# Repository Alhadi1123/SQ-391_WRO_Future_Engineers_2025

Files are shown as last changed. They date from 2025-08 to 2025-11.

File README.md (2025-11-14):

<center><h1> SQ-391 WRO 2025 </center>
<p align="center">
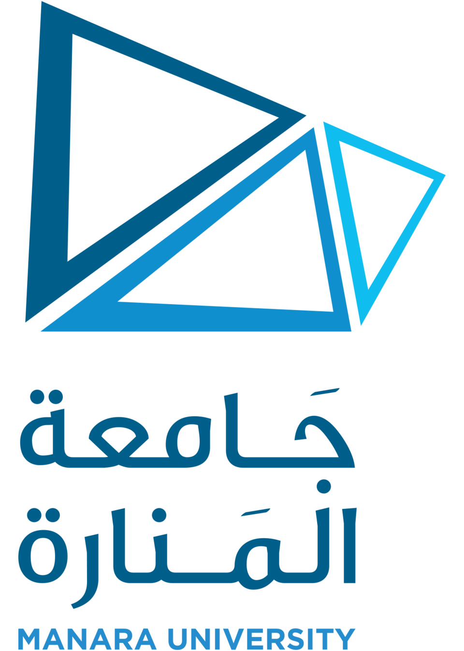
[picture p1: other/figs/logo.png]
  
</p>

<p align="center">
  <a href="https://manara.edu.sy/index.php?lang=1">
    
  </a>
  <a href="https://www.facebook.com/share/1FbUMCjNEs/">
    
  </a>
  <a href="https://www.instagram.com/manarauni?igsh=OWlpZjd6Nm52ZmV3">
    
  </a>
</p>

This repository contains the documentation for the SQ-391 team's robot for the 2025 World Robot Olympiad Future Engineers competition. The robot was designed and built by a team of three students and one coach.

## Table of Contents

- [The Team](#team)
- [The Challenge](#challenge)
- [The Robot](#robot-image)
- [Performance Video](#video)
- [Mobility Management](#mobility-management)
  - [Vehicle Main Body](#vehicle-main-body)
    - [3D Designed Parts](#3d-designed-parts)
  - [Motion Mechanism](#motion-mechanism)
    - [Ackermann Steering Mechanism](#ackermann-steering-mechanism)
    - [Differential Gear](#differential-gear)
    - [Motor Driver](#motor-driver)
  - [Wheels](#wheels)
  - [Engineering Principles](#engineering-principles)
- [Power and Sense Management](#power-and-sense-management)
  - [Electronic Parts](#electronic-parts)
  - [Overall Circuit Usage](#overall-circuit-usage)
  - [Circuit Grounding](#circuit-grounding)
  - [Power Supply](#power-supply)
  - [Overall Scheme](#overall-scheme)
  - [Wiring Diagram](#wiring-diagram)
  - [Assembly List](#assembly-list)
  - [Shopping List](#shopping-list)
- [Obstacle Management](#obstacle-management)
  - [ROS Architecture](#ros-architecture)
  - [Open Challenge](#open-challenge)
  - [Image Processing](#image-processing)
  - [Obstacle Challenge](#obstacle-challenge)
  - [Problems We Encountered](#problems-we-encountered)
- [Suggestions and Future Modifications](#suggestions-and-future-modifications)
- [Resources](#resources)

---

## The Team 

### Alhadi Zidan

<p align="center">
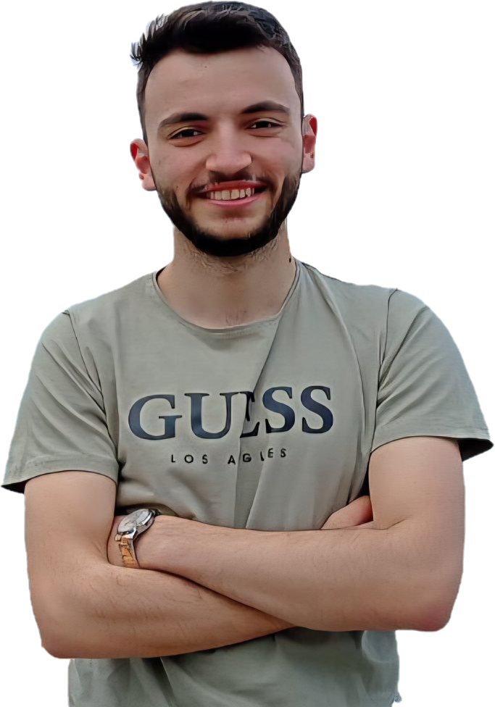
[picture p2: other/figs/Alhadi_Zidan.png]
Alhadi Zidan
  
</p>

**Role:** Coach

**Age:** 22

**Description:** Robotics and Intelligent Systems Engineer - AlManara University.

---

### Ammar Daher

<p align="center">
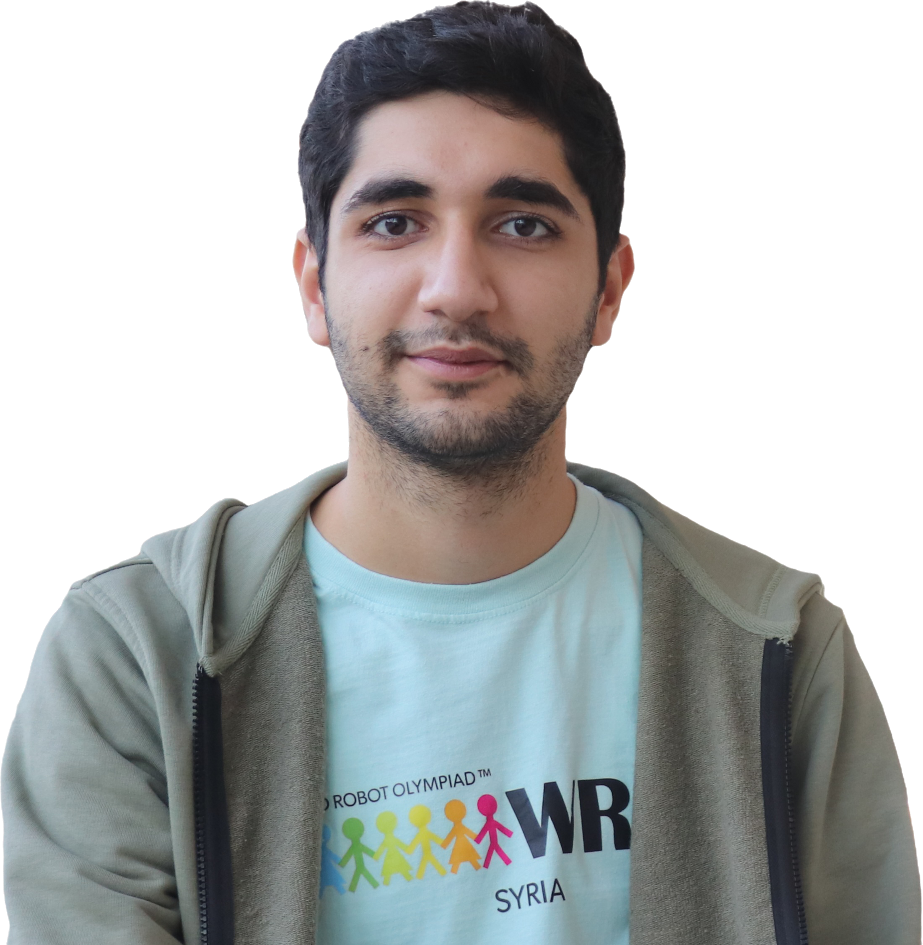
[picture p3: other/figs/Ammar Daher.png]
Ammar Daher
  
</p>

**Age:** 21

**Description:** Robotics and Intelligent Systems student at AlManara University (fifth year).

---

### Lama Alsakher

<p align="center">
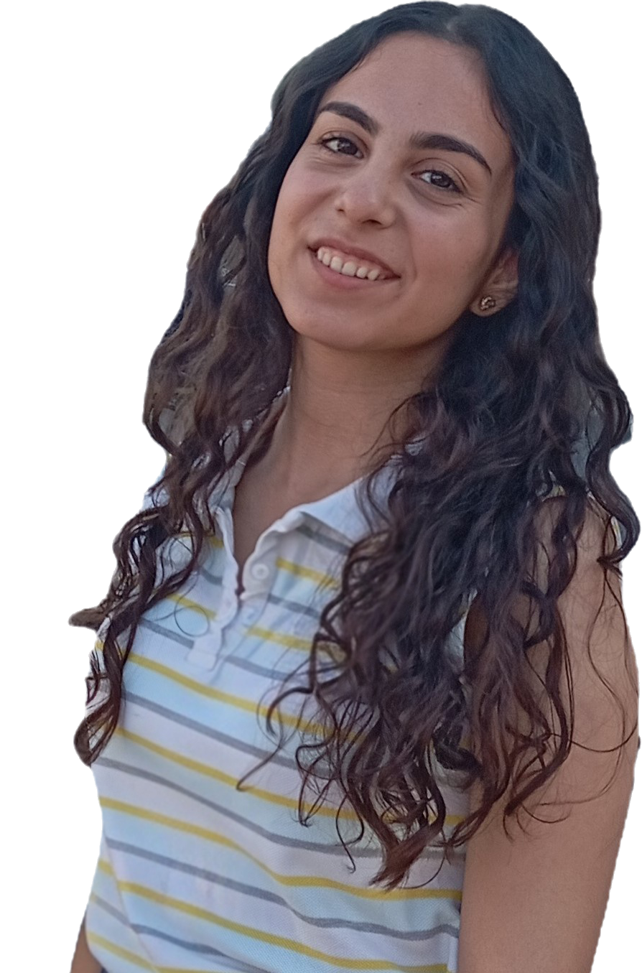
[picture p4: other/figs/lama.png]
Lama Alsakher
  
</p>

**Age:** 20

**Description:** Robotics and Intelligent Systems student at AlManara University (third year).

---

### Ibrahim Alsheikh

<p align="center">
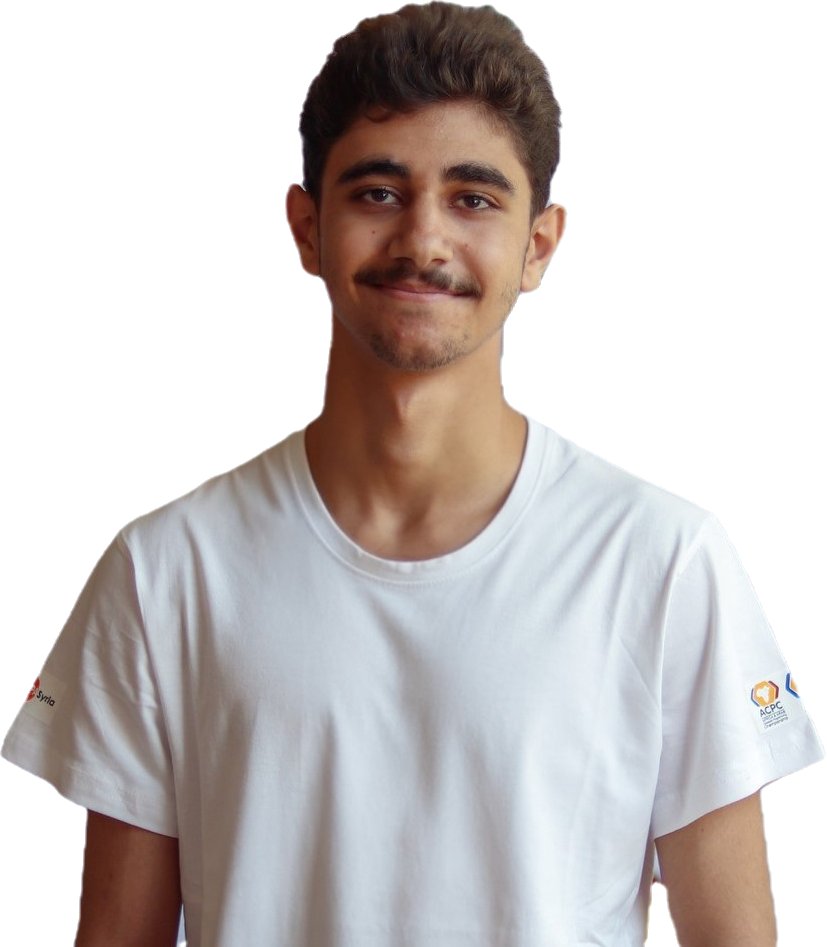
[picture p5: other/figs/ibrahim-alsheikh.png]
Ibrahim Alsheikh
  
</p>

**Age:** 20

**Description:** Robotics and Intelligent Systems student at AlManara University (third year).

---

### Team photo

<p align="center">
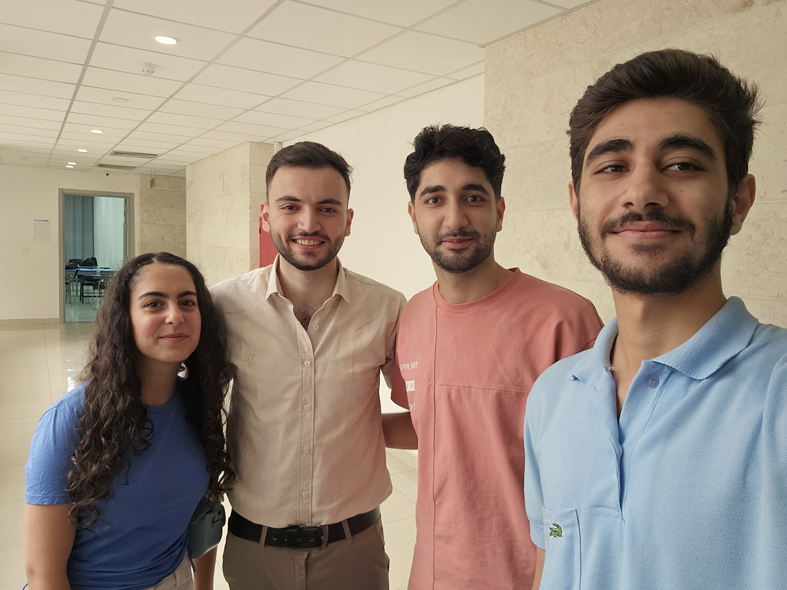
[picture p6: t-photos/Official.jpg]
Team
  
</p>

## The Challenge 

The **[WRO 2025 Future Engineers - Self-Driving Cars](https://wro-association.org/)** challenge invites teams to design, build, and program a robotic vehicle capable of driving autonomously on a racetrack that changes dynamically for each round. The competition includes two main tasks: completing laps while navigating randomized obstacles and successfully performing a precise parallel parking maneuver.

Our approach emphasizes:

- **Advanced Navigation:** Using ROS (Robot Operating System) for real-time sensor fusion and control
- **Computer Vision:** HSV-based color detection for pillar identification
- **Precision Mechanics:** Ackermann steering geometry for optimal maneuverability
- **Robust Engineering:** Systematic approach to power management and component integration

Learn more about the challenge [here](https://wro-association.org/wp-content/uploads/WRO-2025-Future-Engineers-Self-Driving-Cars-General-Rules.pdf).

## Photos of our robot 

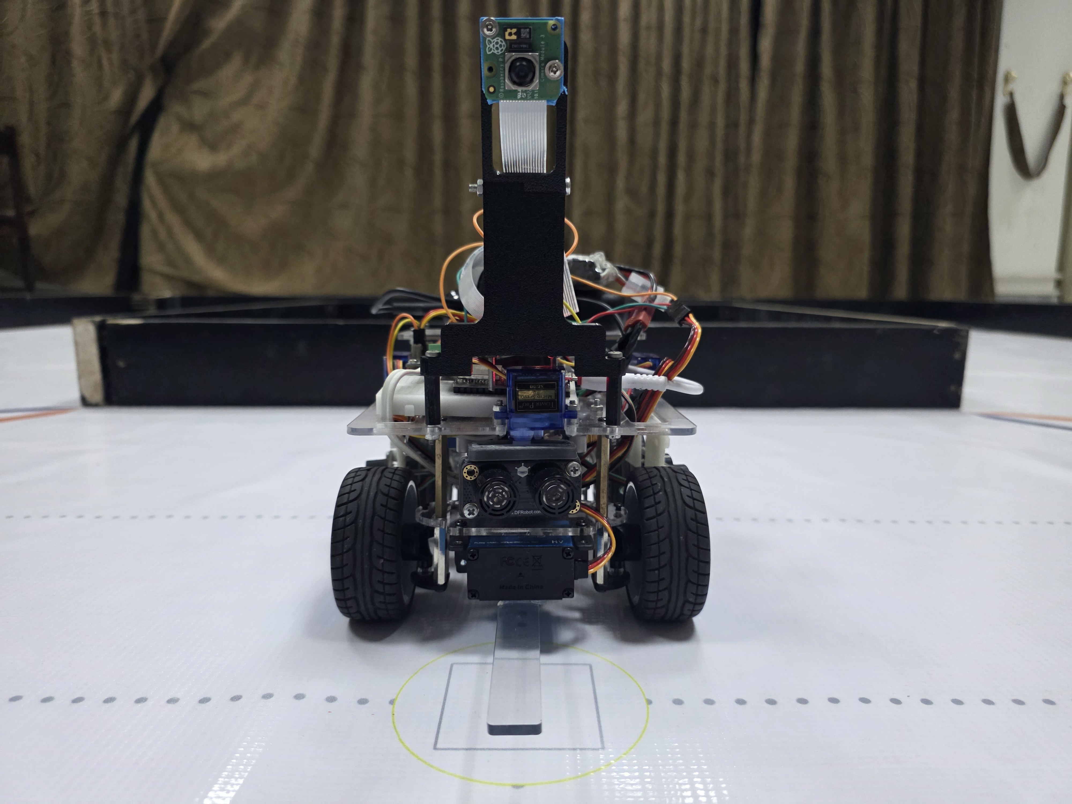
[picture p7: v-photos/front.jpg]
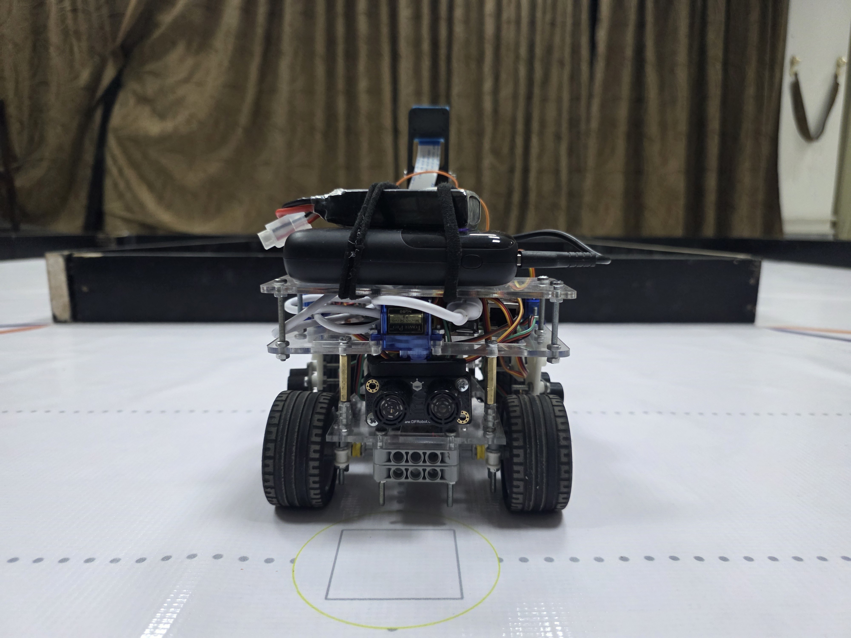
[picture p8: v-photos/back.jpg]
|  |    |
| :---: | :---: |
| _Front_ | _Back_ |
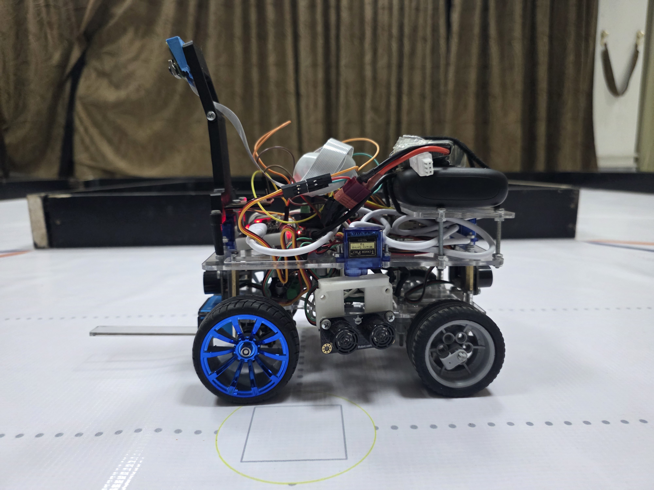
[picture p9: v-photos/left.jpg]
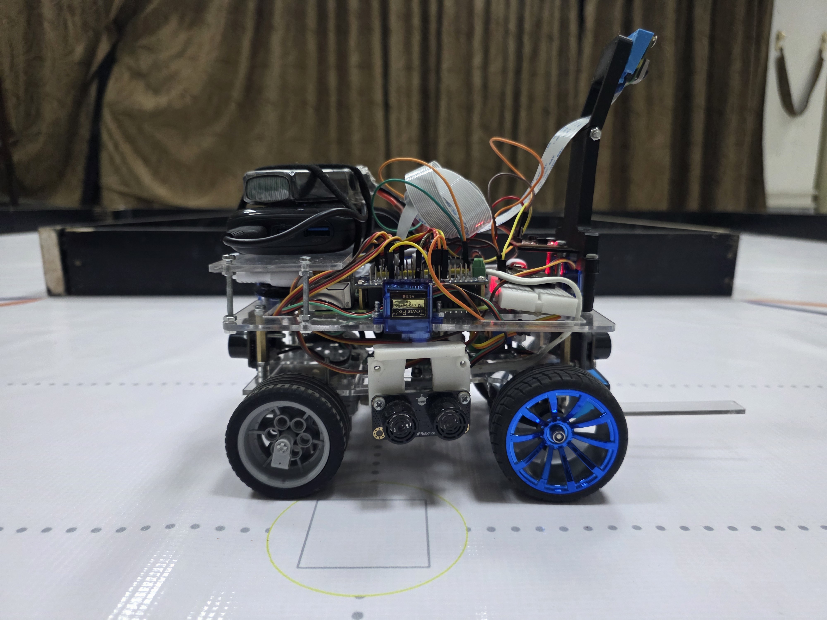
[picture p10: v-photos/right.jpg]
|   |   |
| _Left_ | _Right_ |
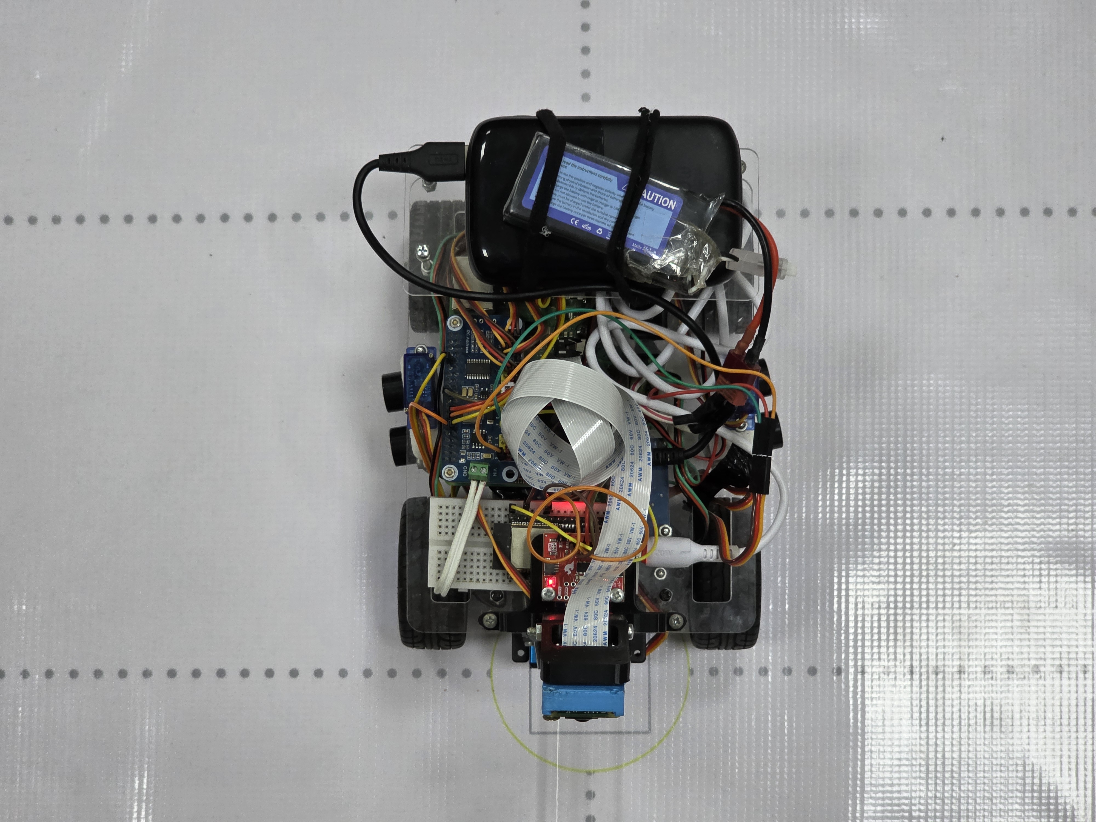
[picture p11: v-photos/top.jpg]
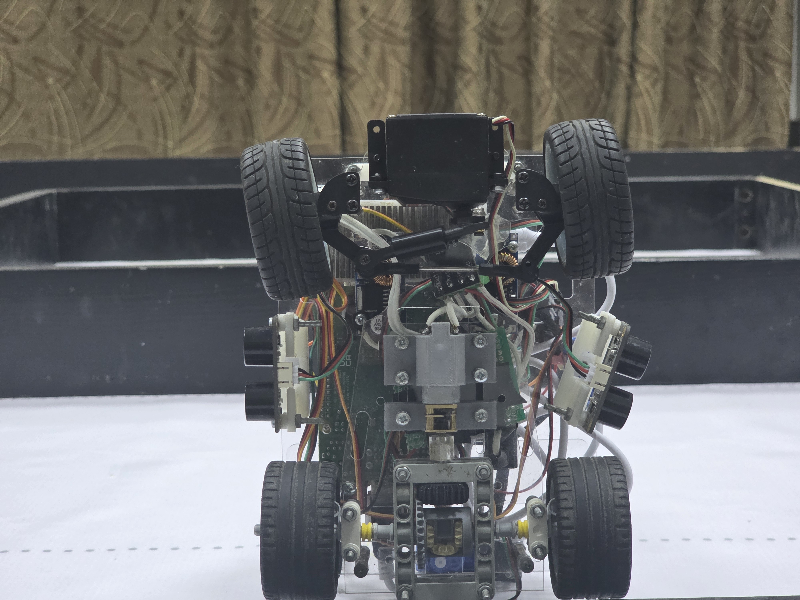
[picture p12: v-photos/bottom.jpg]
|    |  |
| _Top_ | _Bottom_ |

<br>

## Our video of the robot 

<br>
See the <a href='https://youtu.be/9q8Mh4K1foA'> Open Challenge <a/> and the <a href='https://youtu.be/HPLHJcNXbuk'> Obstacle Challenge <a/>

# Mobility Management 

## Vehicle Main Body 

Our robot is a four-wheeled vehicle constructed from two layers of Plexiglass. The upper layer accommodates the primary control and processing units, including the microprocessors, controllers, actuators, and the camera. The lower layer is dedicated to the navigation system and electrical circuit. Sensors and camera are placed in specific positions to detect the surrounding environment.

### 3D Designed Parts 

All components were designed using SOLIDWORKS. The structural parts (base and upper layer) were precision-cut using a CNC laser machine, while functional components were 3D-printed in PLA.

#### Base Layer

A structural base layer that provides mounting for the Ackermann steering and differential mechanisms on its bottom face and hosts the electronic circuit assembly on its top face.

#### Upper Layer

A structural layer that provides mounting for DC-DC converters on its underside and accommodates the Raspberry Pi, ESP, power bank, and camera assembly on its top surface. It also holds servo motors that rotate ultrasonic sensors.

#### Custom 3D-Printed Components

- **Lego-axle to DC motor axle coupler** - High precision interface connecting DC motor shaft to Lego axle.
- **Ultrasonic Sensor Holder** - Secures ultrasonic sensors to servo motors for directional scanning.
- **Camera Holder** - Two-part assembly with integrated IMU mounting.
- **DC Motor Holder** - Rigid mount that fixes the motor to the robot’s structure.
- **Support Wall** - Structural connector between chassis layers.

## Motion Mechanism 

### Ackermann Steering Mechanism 

Our design incorporates an Ackermann steering mechanism for efficient and responsive steering performance. This setup improves handling during turns and helps reduce tire wear by ensuring that each wheel follows its proper path around a corner. The inner wheel turns at a sharper angle than the outer one, allowing the robot to turn more naturally and maintain better traction.

**Key Mathematical Relations:**

For wheelbase L, front track t, and turn radius R, the ideal relations are:

```
tan(δ_in) = L/(R - t/2)
tan(δ_out) = L/(R + t/2)
```

**Steering Ratio:** The relationship between servo input angle and resulting road-wheel angle:

```
SR = θ_input / δ_avg
δ_avg ≈ θ_input / SR
```

**Servo Torque:** Required actuator torque:

If M_req is the required steering moment at the road-wheel side, η is the mechanism efficiency (typically 0 <η ≤ 1), then:

```
τ_servo ≈ M_req / (SR × η)
```

**Turning Radius:**

```
R ≈ L / tan(δ_avg)
```

### Differential Gear 

We implemented a differential gearbox system that ensures the rear wheels can spin at different rates while maintaining balanced power distribution. This component plays a crucial role in maintaining smooth and controlled movement, particularly when the robot is turning or when one wheel has less traction than the other. By balancing the torque between both wheels, the differential gear helps prevent skidding and ensures stable movement. We started by using LEGO gears, but because of their low stability, we decided to design and illustrate a customized ring gear by 3d printing and implement it in the mechanism. 

**Components:**

- Ring Gear: Large gear receiving power from the motor
- Pinion Gear: Smaller gear connecting to the drive shaft
- Side Gears: Two gears linking the differential to the axle shafts
- Spider Gears: Allow wheels to rotate at varying speeds

**Gear Ratio Calculation:**

```
GR = R/S1 + R/S
```

Where R is ring gear teeth, S1 and S2 are side gear teeth.

The wheel speed (N_wheel) can be derived from the motor’s no-load speed (N_Motor_no_load) using the formula:

```
N_wheel = N_Motor_no_load / GR
```

### Motor Driver 

The DRV8871 H-bridge motor driver provides:

- **Current Capability:** Up to 3.5A continuous, 3.6A peak
- **Voltage Range:** 6.5-45V input
- **PWM Control:** 0-200kHz recommended frequency
- **Protection:** Overcurrent, thermal shutdown, undervoltage lockout
- **Control:** Simple two-pin interface (IN1, IN2)

## Wheels 

**Specifications:**

- **Diameter:** 65mm
- **Width:** 25-30mm
- **Material:** Rubber tire with plastic hub
- **Weight:** Lightweight for optimal performance (20-21 g)
- **Coupling:** Compatible with hex connections

## Engineering Principles 

1. **Torque and Speed Balance:** Motor selection based on τ = F × r relationship
2. **Power Output:** Verification using P = τ × ω, providing 4.2W sufficient power
3. **Weight Distribution:** Strategic component placement for stability
4. **Maneuverability:** Differential drive system with ~0.1m turning radius
5. **Energy Efficiency:** Optimized gear ratios for peak efficiency operation

# Power and Sense Management 

## Electronic Parts 

### ESP32-WROOM-32E

| **Feature** | **Details / Image** |
|---|---|
| **Core** | Dual-core Xtensa® LX6 up to 240 MHz |
| **Memory** | 520 KB SRAM, 4 / 8 / 16 MB QSPI flash, optional 2 MB PSRAM |
| **Wireless** | Wi-Fi 802.11 b/g/n (2.4 GHz), Bluetooth 4.2 + BLE |
| **I/O** | Up to 26 GPIOs (3.3 V), 2× 12-bit ADC, 2× 8-bit DAC, 10 touch inputs |
| **Interfaces** | UART × 3, SPI × 4, I²C × 2, I²S, PWM, CAN (TWAI), SD/MMC, Ethernet MAC |
| **Supply** | 3.0 – 3.6 V (typ. 3.3 V), ≥ 500 mA recommended |
| **Operating Temp** | −40 °C to 85 °C (105 °C for H variants) |
| **Programming** | UART-based flashing via CP2102 / CH340 bridge |
| **Form Factor** | 18 × 25.5 × 3.1 mm, 38 castellated pads |
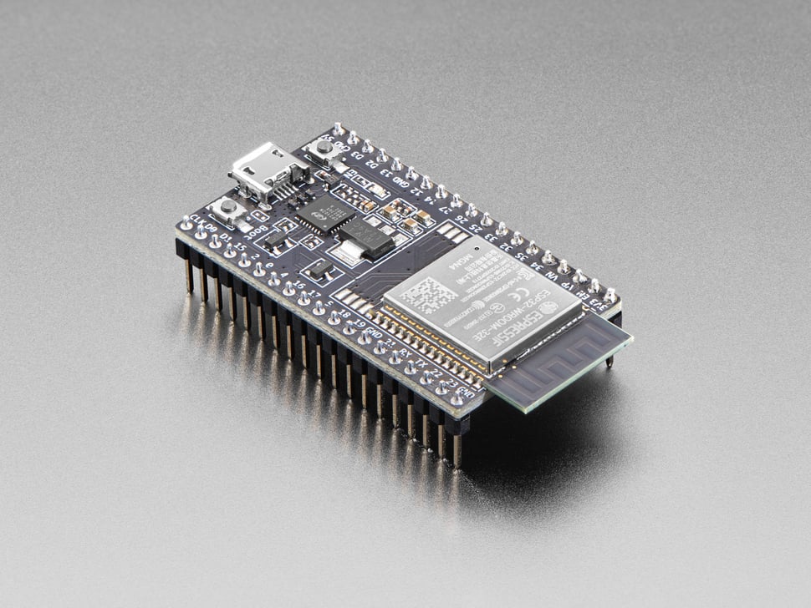
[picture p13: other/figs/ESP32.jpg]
ESP32-WROOM-32E
| **Image** | <div align="center"> |

### Raspberry Pi 4 Model B

| **Feature** | **Details / Image** |
|---|---|
| **Processor** | Broadcom BCM2711, quad-core Cortex-A72 (ARM v8) 64-bit SoC @ 1.5 GHz |
| **Memory** | Up to 8 GB LPDDR4 RAM |
| **Connectivity** | Dual-band Wi-Fi (2.4/5.0 GHz 802.11b/g/n/ac), Bluetooth 5.0 + BLE, Gigabit Ethernet |
| **USB Ports** | 2 × USB 3.0, 2 × USB 2.0 |
| **GPIO** | 40-pin header (backward-compatible with earlier boards) |
| **Video & Sound** | 2 × micro HDMI (up to 4Kp60), MIPI DSI/CSI, 4-pole audio + video jack |
| **Multimedia** | H.265 4Kp60 decode, H.264 1080p60 decode / 1080p30 encode, OpenGL ES 3.0 |
| **Storage** | Micro SD card slot for OS and data |
| **Power Input** | 5 V DC via USB-C (≥ 3 A) or GPIO header; PoE supported (via PoE HAT) |
| **Environment** | Operating temperature 0–50 °C; in production until ≥ 2034 |
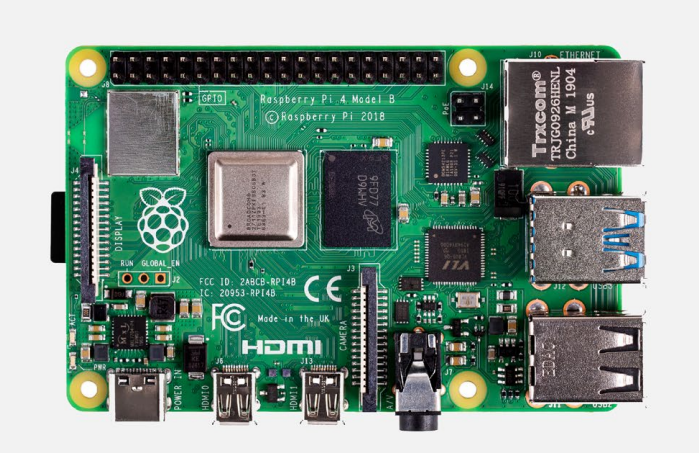
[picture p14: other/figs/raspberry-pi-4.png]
Raspberry Pi 4
| **Image** | <div align="center"> |

### Raspberry Pi Camera Module 3

| **Feature** | **Details / Image** |
|---|---|
| **Sensor** | Sony IMX708, 11.9 MP, 4608 × 2592 px (1/2.43″ optical size) |
| **Pixel Size** | 1.4 µm × 1.4 µm |
| **Focus** | Motorized, depth of field ≈ 5 cm – ∞ |
| **Focal Length** | 2.75 mm, F / 2.2 |
| **Field of View** | 102° (H) × 67° (V) |
| **Max Exposure** | 112 s |
| **Video Modes** | 2304 × 1296 @ 56 fps, 2304 × 1296 @ 30 HDR, 1536 × 864 @ 120 fps |
| **Size / Weight** | 25 × 24 × 12.4 mm; ≈ 4 g |
| **NoIR Version** | Unavailable |
| **Interface** | CSI connector (Raspberry Pi compatible) |
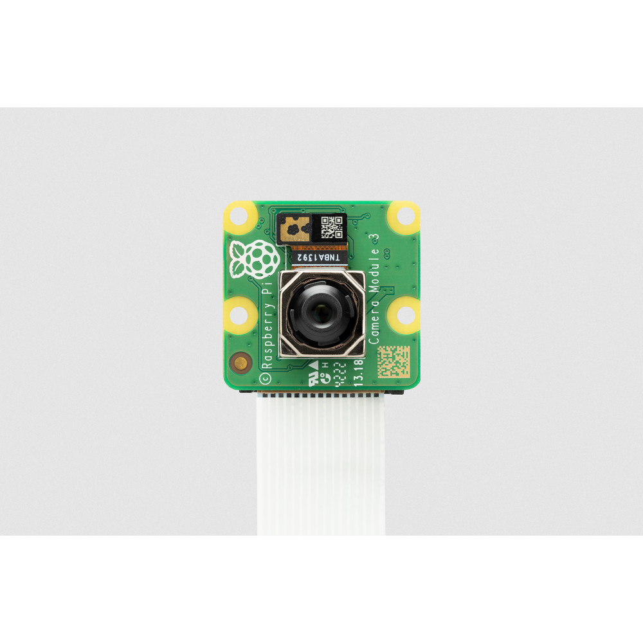
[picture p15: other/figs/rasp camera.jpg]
Raspberry Pi Camera Module 3
| **Image** |  |

### BN0086 (Qwiic) IMU Sensor

| **Feature** | **Details / Image** |
|---|---|
| **Type** | 9-DoF IMU – 3-axis accelerometer, 3-axis gyroscope, 3-axis magnetometer |
| **Sensor Fusion** | On-chip Cortex-M0+ running SH-2 firmware (quaternion + rotation vector output) |
| **Interfaces** | I²C (Qwiic, 3.3 V logic, up to 400 kHz), SPI, UART |
| **I²C Address** | 0x4B (default), optional 0x4A via solder jumper |
| **Output Data** | Rotation Vector (9-axis), Game Rotation (6-axis), Linear Accel, Gravity, Raw Sensor Data |
| **Supply Voltage** | 3.3 V (Qwiic connector) |
| **Interrupt** | INT pin for event-driven reporting; configurable update rate (tens–hundreds Hz) |
| **Calibration** | Auto gyro/accel bias; magnetometer requires hard/soft-iron calibration |
| **Mounting** | Align IMU frame (X,Y,Z) with robot frame; minimize vibration and magnetic interference |
| **Use Case** | Absolute and relative orientation tracking for robotics, mapping, and navigation |
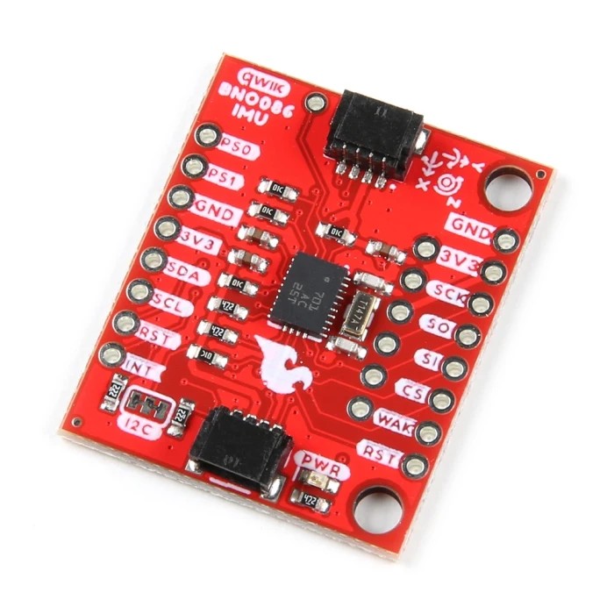
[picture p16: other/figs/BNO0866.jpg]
BN0086 (Qwiic) IMU Sensor
| **Image** |  |

### DRV8871 Motor Driver

| **Feature** | **Details / Image** |
|---|---|
| **Type** | Single H-bridge brushed DC motor driver (Texas Instruments) |
| **Topology** | Full H-bridge using 4 N-MOSFETs; R<sub>DS(on)</sub> ≈ 565 mΩ |
| **Current Capability** | Up to 3.5 A continuous, 3.6 A peak |
| **Supply Voltage (VM)** | 6.5 – 45 V |
| **Control Inputs** | IN1 / IN2 logic pins (forward, reverse, brake, coast) |
| **Logic Levels** | 0 – 5.5 V; internal pulldowns ≈ 100 kΩ |
| **PWM Control** | 0 – 200 kHz; effective duty range ≈ 16 – 84 |
| **Current Regulation** | Integrated sensing; programmable limit via ILIM resistor |
| **Protections** | UVLO, overcurrent (OCP ≈ 3.7 – 6.4 A), thermal shutdown (TSD) |
| **Package** | 8-pin HSOP (DDA) with PowerPAD™ (≈ 4.9 × 6.0 mm) — tie pad to GND plane |
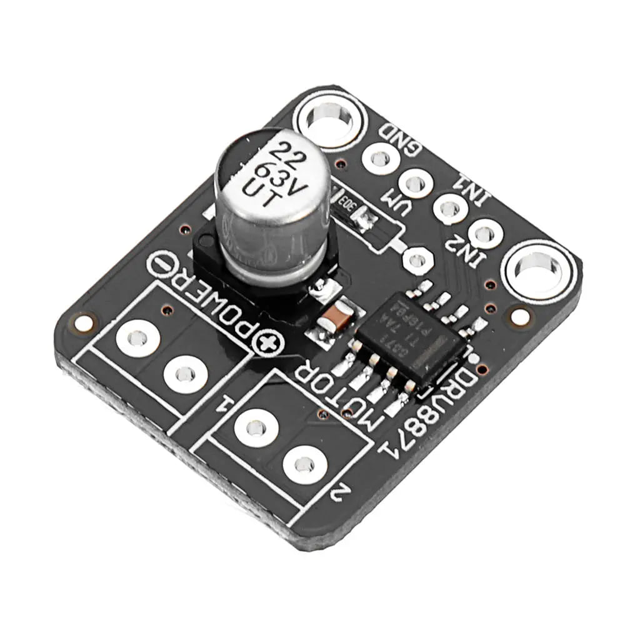
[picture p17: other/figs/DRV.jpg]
DRV8871 Motor Driver
| **Image** |  |

### URM09 Ultrasonic (Trig)

| **Feature** | **Details / Image** |
|---|---|
| **Type** | Ultrasonic distance sensor (single-wire Trig/Echo via TDM) |
| **Range** | 2 – 500 cm |
| **Resolution** | 1 cm; Accuracy ≈ 1 |
| **Measurement Rate** | Up to 25 Hz (Trig variant) |
| **Interface** | Single digital I/O (Trig + Echo multiplexed) |
| **Timing** | 10 µs trigger pulse; max echo ≈ 35 ms |
| **Supply Voltage** | 3.3 – 5.5 V; Current < 20 mA |
| **Field of View** | ≈ 60° beam angle |
| **Size** | 47 × 22 mm (3-pin PH2.0 connector: +, –, D) |
| **Integration Notes** | Fire one sensor at a time; wait > 40 ms between pings to avoid cross-talk |
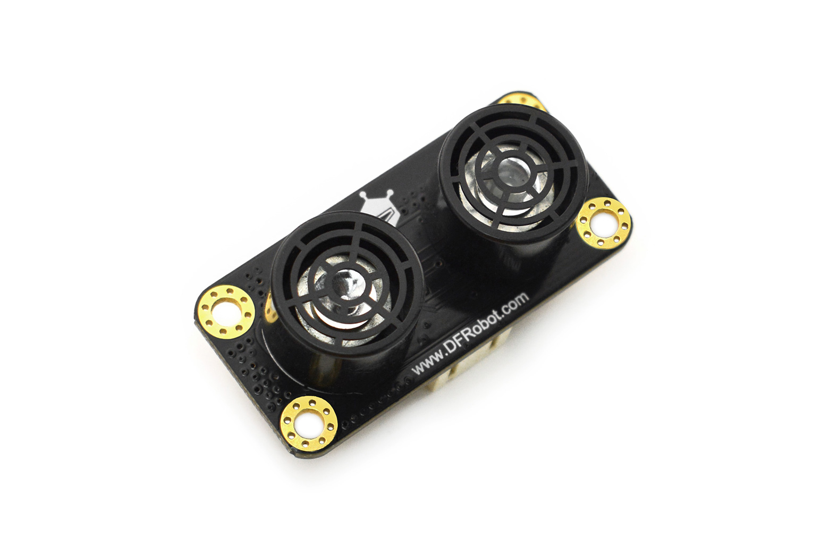
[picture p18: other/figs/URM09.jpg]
URM09 Ultrasonic (Trig)
| **Image** |  |

### Core DC Motor (6 V, 400 RPM)

| **Feature** | **Details / Image** |
|---|---|
| **Type** | Brushed DC motor with metal gearbox (carbon brushes) |
| **Nominal Voltage** | 6 V DC |
| **Gear Ratio** | 48 : 1 |
| **No-Load Speed** | ≈ 400 RPM ; No-Load Current ≈ 120 mA |
| **Torque** | Continuous ≈ 1.2 kg·cm (0.118 N·m), Stall ≈ 3.9 kg·cm (0.382 N·m) |
| **Stall Current** | ≈ 3.2 A |
| **Mechanical** | Size ≈ 47 × 15 × 10 mm ; Weight ≈ 21 g ; 3 mm D-shaft (8 mm L) |
| **Recommended Driver** | H-bridge ≥ 3.2 A peak, PWM speed control (tens kHz range) |
| **Notes** | Operable up to 15 V (short duration) ; avoid stall for thermal safety |
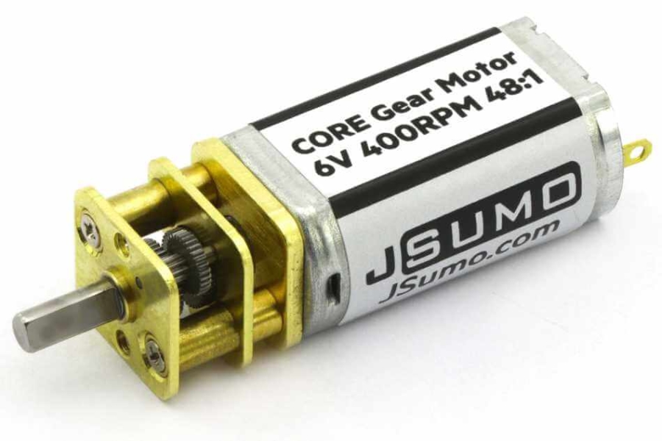
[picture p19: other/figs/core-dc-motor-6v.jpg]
Core DC Motor 6V 400RPM
| **Image** |  |

### TowerPro MG996R Servo

| **Feature** | **Details / Image** |
|---|---|
| **Type** | High-torque, metal-gear hobby servo |
| **Operating Voltage** | 4.8 V – 7.2 V |
| **Stall Torque** | 12 kg·cm (at 6 V) |
| **Speed** | 0.2 s / 60° (at 6 V) |
| **Control Signal** | Standard PWM (1 – 2 ms pulse width) |
| **Gear Type** | All-metal gears for durability and strength |
| **Dimensions** | 40.7 × 19.7 × 42.9 mm ; Weight ≈ 55 g |
| **Connector** | JR (universal 3-pin type) |
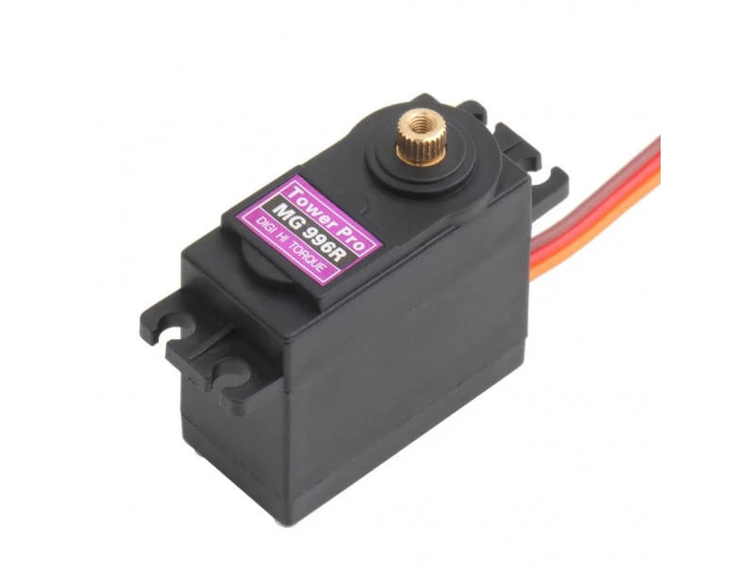
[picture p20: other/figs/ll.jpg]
TowerPro MG996R Servo
| **Image** |  |

### Micro Servo Motor SG90

| **Feature** | **Details / Image** |
|---|---|
| **Type** | 9 g micro servo with plastic gears and PWM control |
| **Operating Voltage** | 4.8 – 6.0 V (nominal 5 V) |
| **Rotation Range** | ≈ 180° mechanical (160–170° usable via PWM) |
| **Speed** | ≈ 0.12 s / 60° at 4.8 V |
| **Torque** | ≈ 1.8 kg·cm (0.176 N·m) at 4.8 V |
| **Current Draw** | 10–15 mA idle, 100–250 mA typical, ≥ 650 mA stall |
| **Dimensions** | 22.8 × 12.2 × 29.4 mm ; Weight ≈ 9 g |
| **Control Signal** | 50 Hz PWM (1.0–2.0 ms pulse width, 1.5 ms center) |
| **Mounting** | Includes horns and screws; Futaba-compatible 21T spline (4.8 mm) |
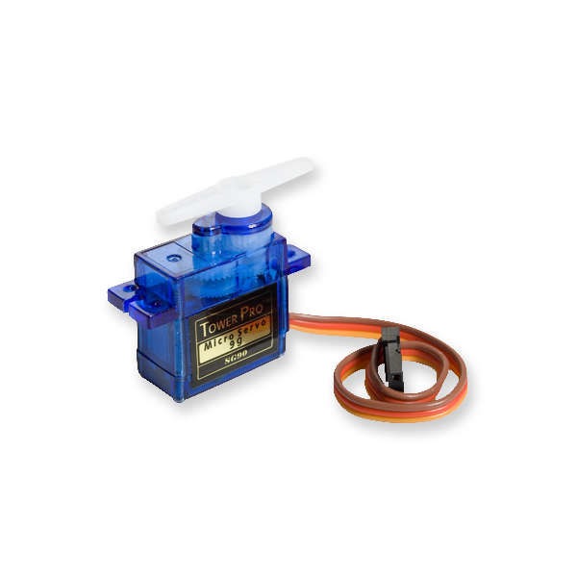
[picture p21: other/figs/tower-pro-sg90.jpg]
Micro Servo Motor SG90
| **Image** |  |

### PCA9685 Servo Driver HAT

| **Feature** | **Details / Image** |
|---|---|
| **Controller** | PCA9685 – 16-channel, 12-bit PWM generator with I²C interface |
| **PWM Frequency** | Programmable 24 Hz – 1.5 kHz ; use 50–60 Hz for hobby servos |
| **Resolution** | 12-bit (4096 steps) → 4.88 µs per step @ 50 Hz |
| **Servo Rail Voltage** | 5 V (up to 3 A continuous total output) |
| **Input Power** | 5 V from Pi header (light load) or 6–12 V via VIN (recommended) |
| **I²C Bus** | 3.3 V logic; default address 0x40; A0–A4 jumpers for stacking (up to 32 devices) |
| **Isolation** | For high-current servos, cut 0 Ω link and power via VIN while isolating Pi 5 V |
| **Form Factor** | 65 × 30 mm HAT ; 3 mm mounting holes ; straight or right-angle header variant |
| **Integration Notes** | Calibrate servo end-stops ; ensure bulk capacitors on 5 V line |
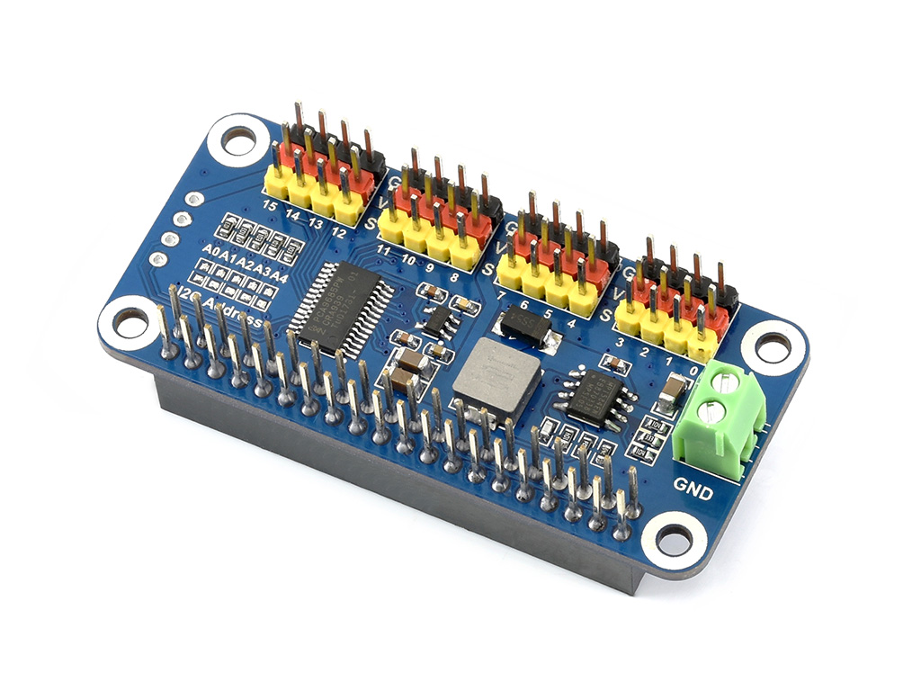
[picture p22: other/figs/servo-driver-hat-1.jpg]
PCA9685 Servo Driver HAT
| **Image** |  |

### Power Supply Components

- **Primary Battery:** 2S LiPo (7.4V, 2200mAh, 50C) with Deans connector
- **Raspberry Pi Power:** INIU 10,000mAh USB-C power bank (22.5W)
- **Voltage Regulation:** XL4005 DC-DC step-down converters
- **Current Distribution:** PCA9685 servo driver board

## Overall Circuit Usage 

Our power management strategy employs dual power domains:

1. **Control Domain:** Raspberry Pi powered by dedicated USB power bank
2. **Actuation Domain:** Motors and sensors powered by a LiPo battery

**Current Specifications:**

| Component | Supply Voltage | Idle Current | Active Current | Peak Current |
| --- | --- | --- | --- | --- |
| Raspberry Pi 4 | 5.1V | ~540mA | ~1.0-1.3A | up to 3.0A |
| Camera Module  | 5V | -- | ~200-250mA | ~300-350mA |
| ESP32 | 3.3V | <5µA | ~50-80mA | ~120-200mA |
| BNO086 IMU | 3.3V | ~3mA | ~3-10mA | -- |
| URM09 Sensors  | 5V | -- | <20mA | -- |
| MG996R Servo | 6V | ~10-20mA | ~500-900mA | ~2.0-2.5A |
| Core DC Motor  | 6V | -- | ~200-400mA | ~2.2A |

## Circuit Grounding 

Proper grounding ensures stable operation by providing a common electrical reference point for all components. Our star-grounding scheme minimizes electrical noise and prevents ground loops that could affect sensor readings.

## Power Supply 

The separated power architecture prevents motor-induced voltage drops from affecting the Raspberry Pi, ensuring uninterrupted operation of the control system during high-current motor operations.

## Overall Scheme 

<p align="center">
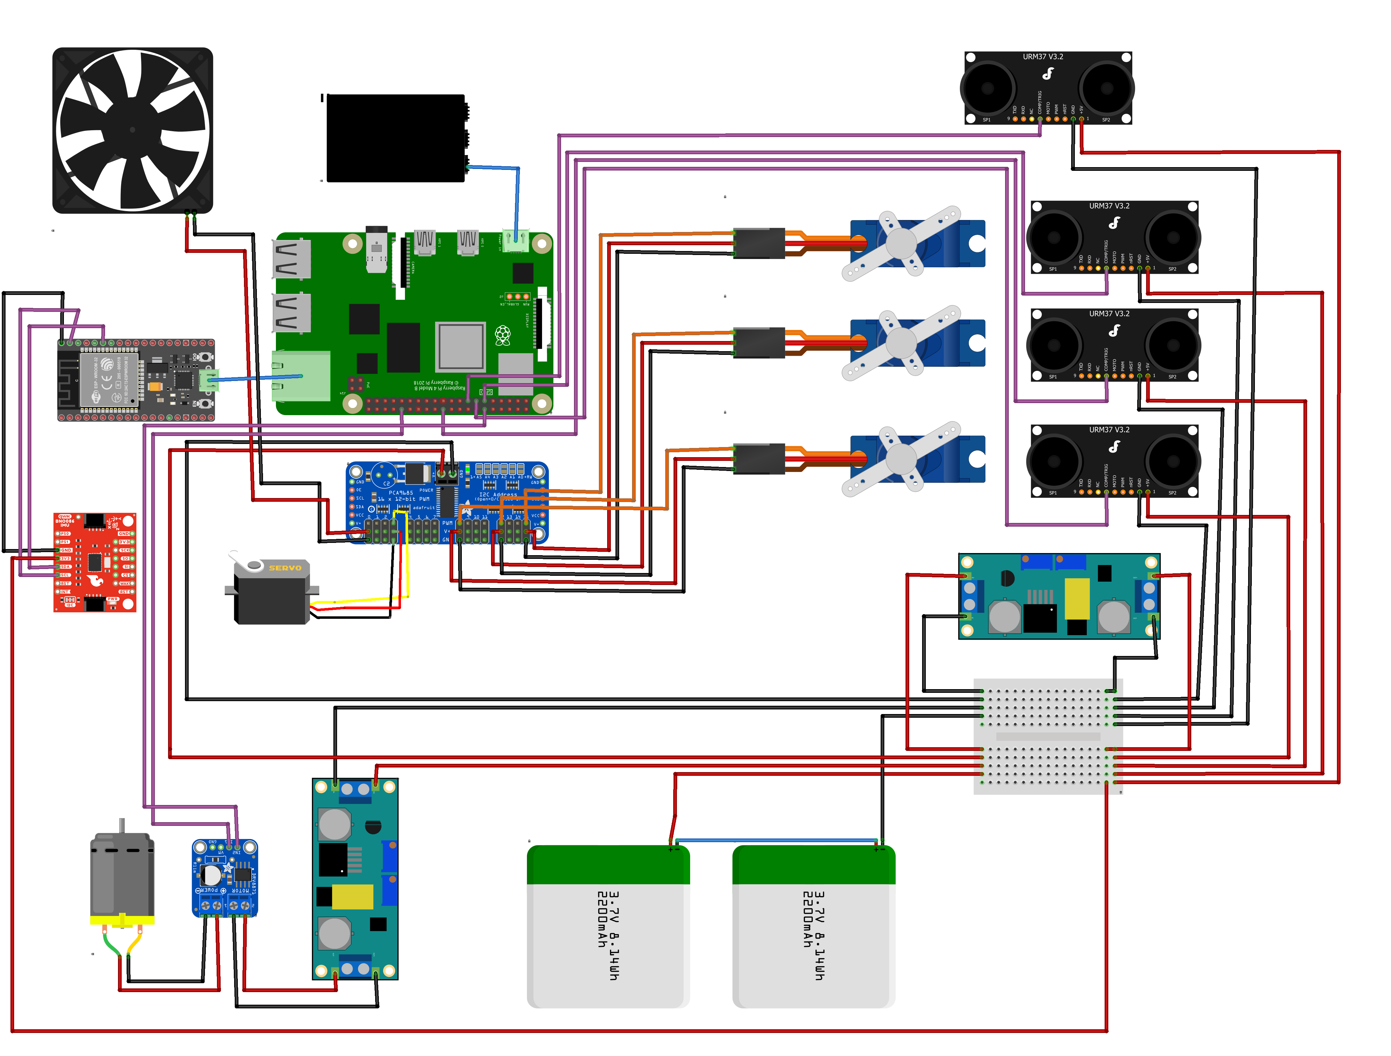
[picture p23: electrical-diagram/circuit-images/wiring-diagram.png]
  
</p>

## Wiring Diagram 

<p align="center">
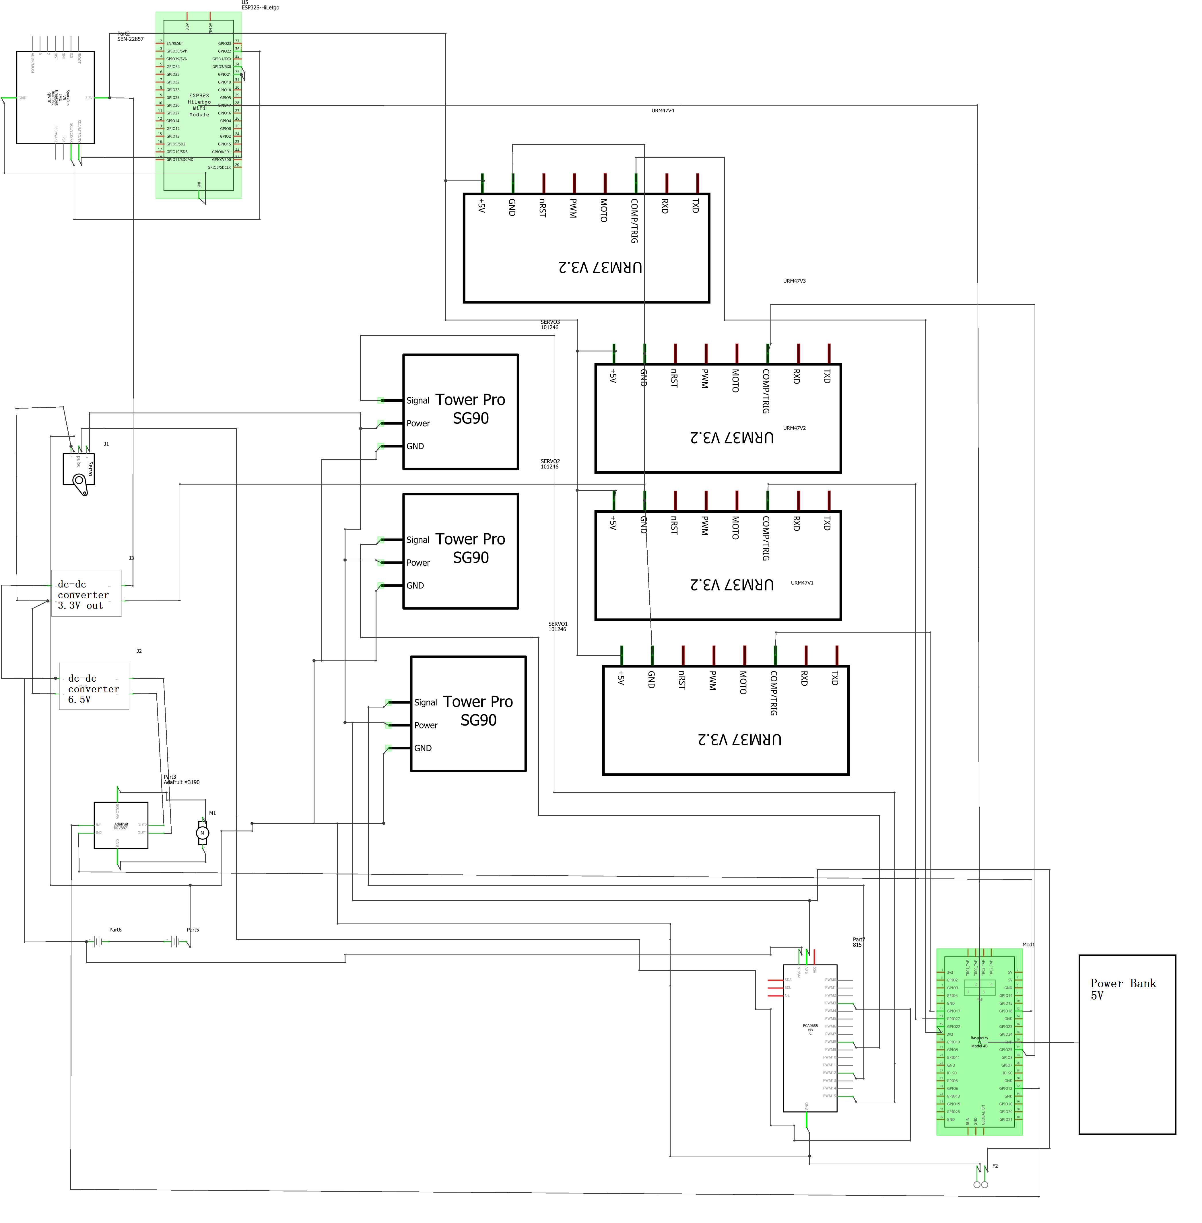
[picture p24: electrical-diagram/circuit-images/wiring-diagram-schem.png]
  
</p>

## Assembly List 

| Label | Part Type | Properties |
| --- | --- | --- |
| Mod1 | Raspberry Pi 4B  | BCM2711 Quad-core Cortex-A72 @1.5GHz |
| U5 | ESP32S-HiLetgo | 38 pins, NudeMCU-32S variant |
| Part2 | SparkFun BNO086  | VR IMU Breakout (Qwiic) |
| Part3 | Adafruit DRV8871 | H-bridge motor driver |
| Part7 | PCA9685 | PWM/Servo breakout board |
| M1 | JSUMO Core Motor | 6V 400 RPM with 48:1 gearing |
| J1 | TowerPro MG996R  | High-torque servo motor |
| SERVO1-3 | TowerPro SG90 | Micro servo motors |
| URM1-4 | URM09 | Ultrasonic distance sensors |
| Part4 | INIU Power Bank  | 10,000mAh USB-C in/out |
| Part5-6  | LiPo Battery | 2200mAh 2S configuration |

## Shopping List 

| Qty | Part | Unit Price (€) | Total (€)  |
| --- | --- | --- | --- |
| 1 | Raspberry Pi 4B (4GB) | 61.08 | 61.08 |
| 1 | ESP32 Dev Kit | 11.49 | 11.49 |
| 1 | SparkFun BNO086 | 49.90 | 49.90 |
| 1 | Adafruit DRV8871 | 7.68 | 7.68 |
| 1 | PCA9685 Servo Board | 40.79 | 40.79 |
| 1 | JSUMO Core Motor | 12.50 | 12.50 |
| 1 | TowerPro MG996R | 12.00 | 12.00 |
| 3 | TowerPro SG90 | 2.99 | 8.97 |
| 4 | URM09 Sensors | 14.50 | 58.00 |
| 1 | Power Bank 10Ah | 29.95 | 29.95 |
| 2 | LiPo 2200mAh | 19.99 | 39.98 |
| 2 | XL4005 DC-DC | 4.92 | 9.84 |
| 1 | Cooling Fan | 1.99 | 1.99 |
| **Total** | | | **343.77** |

# Obstacle Management 

Our main algorithm for both challenges relies on the robot’s ability to move to a specified distance (threshold) from the inner or outer wall and then follow that offset to navigate between sections. We achieve this using ultrasonic sensors mounted on SG90 servos that rotate the sensors to face the wall, as shown in the following figure, providing accurate measurements of the robot’s distance on all four sides. To achieve that, we used an IMU sensor (BNO086) to estimate the robot’s angle during a run. Because we have multiple sensors, actuators, and controllers, our software stack is built with ROS Noetic (ROS 1) on Raspberry Pi OS Bookworm (ARM64), which handles real-time acquisition, synchronization, and processing of all sensor streams.

<p align="center">
  case4
</p>

## ROS Architecture 

Our robot utilizes ROS Noetic for real-time sensor fusion and control:

**Node Structure:**

- **Control Node:** Central processing and decision making
- **Ultrasonic Node:** Range measurements at 25Hz
- **IMU Node:** Orientation data via rosserial bridge
- **Camera Node:** On-demand pillar detection service
- **Actuator Nodes:** Motor and servo command execution

**Communication:**

- Topics: `/ultra_sensors`, `/gyro_sensor`
- Services: `/detect_pillars` for vision processing
- Parameters: Dynamic reconfiguration for field tuning

## Open Challenge 

In the Open Challenge, the goal is to complete three laps without touching the walls and in the shortest possible time. We keep the robot centered in the lane by computing the difference between the right and left distance sensors and regulating this error toward zero during navigation. To improve the rate of change of this error, we also regulate the angle error—the difference between the current yaw (robot orientation) and the desired reference. This yields low overshoot when converging to the centerline and smooth motion transitions. To move to the next section, we detect corners using the side ultrasonic sensors, then adjust the desired robot angle reference by ±90° depending on the round direction.

### Navigation Strategy

We employ a dual-error PID controller that regulates the robot's angle and distances from the walls. The `pid_control` function shown below computes the distance error as the difference between the current and desired distances from the inner and outer walls, and the angle error as the difference between the current robot orientation and the desired reference angle. These errors are weighted by their respective proportional gains, kp1 and kp2, to generate a correction value at each control cycle. The final steering angle to be applied is then determined from this correction.

**Error Functions:**

```
e_θ(t) = wrap(θ(t)) - wrap(θ_ref)
e_d(t) = d_R(t) - d_L(t)
```

```python
def pid_control(kp1=0.5,kp2=-0.45,kd2=0,speed=max_speed,threshold=0,dists=[30]*4):
    #PID control loop to adjust steering and maintain distance balance.
    global prev_dist_err,steering, dist_err
    dist_err = dists[l] - dists[r]+threshold*dir1
    angle_err=yaw+float(dir1*sec*90)
    corr=kp1*(angle_err)+(kp2*(dist_err)+kd2*(dist_err-prev_dist_err))*(abs(dist_err)>0)
    
    # Limit correction to safe range
    corr = max(min(corr,25),-25)
    
    steering = steering_angle(corr)
    print(corr, steering)
    move_dc(speed,pi_pwm1,pi_pwm2)
```

**Corner Detection:**

```
max{d_L(t), d_R(t)} > d_corner ≈ 1.0m
```

When the robot reaches the twelfth section, it comes to a full stop based on calibrated distance readings from the front and rear ultrasonic sensors. This process is implemented in the code below.

```python
if sec == 12:
            msg.nums = [0.017,1,1,1]
            pub.publish(msg)
            dis = copy.deepcopy(dists)
            while dists[f]>150 or dists[b]<110:
                pid_control(speed = 80,dists = dis)
                dis = copy.deepcopy(dists)
            stop_dc(0.3)
            break
```

## Image Processing 

Our algorithm depends on capturing five key images during the Obstacle Challenge to detect the colors of the pillars facing the robot. We capture one image as we exit the parking area at the start of the run and four images before each section. After collecting the required data from these images, processing is handled by a ROS service node; each time it is called, it returns a list of detected pillars with their attributes (area, centroid, and color).

### Camera Setup

 We adjust the properties of the camera to handle different lighting conditions as described in the following block.
 
 ```python
 # Initialize PiCamera2
        self.picam2 = Picamera2()
        config = self.picam2.create_preview_configuration(main={'size': (3072, 1792)})
        config['main']['format'] = 'RGB888'  # Use RGB color format
        config['controls']['ExposureTime'] = 20000  # Manual exposure
        config['controls']['AnalogueGain'] = 7      # Manual gain
        self.picam2.configure(config)
        self.picam2.start()
```

### Image Preprocessing

Before isolating the pillars to extract information, it is essential to apply preprocessing to the captured images. This step converts the image data into a form that helps us remove distracting elements that might be mistaken for pillars and identify the colors of objects in the game field, such as pillars and parking borders.

#### HSV Color Space Selection

We convert images from RGB to HSV so we can separate color from brightness. In RGB, each channel mixes chromatic information with luminance, so simple thresholds are very sensitive to lighting changes. HSV—Hue, Saturation, and Value—encodes, in order, the perceived color, its purity, and its brightness. This decoupling makes our color-based steps (masking, thresholding, segmentation) far more stable under shadows, glare, and exposure changes. Main advantages of using HSV are:

- **Lighting Independence:** Hue channel unaffected by illumination changes
- **Intuitive Filtering:** Easy threshold definition for color ranges
- **Robustness:** Better performance under varying environmental conditions

#### Masking

We use the following **Color Thresholds:**

- **Red Pillars:** Lower: [100, 43, 130], Upper: [141, 255, 255]
- **Green Pillars:** Lower: [30, 24, 90], Upper: [76, 213, 255]
- **Pink Parking:** Lower: [122, 87, 181], Upper: [134, 236, 255]

#### Contour Analysis

Contour detection in computer vision is the process of identifying the boundaries or edges of objects within an image. It is fundamental to many image analysis applications, including image segmentation, object recognition, and classification. The cv2 functions we used are mentioned in the following block.

```python
cv2.contourArea(contour)      # Object area calculation
cv2.boundingRect(contour)     # Bounding rectangle
cv2.moments(contour)          # Centroid computation
```

## Obstacle Challenge 

In the Obstacle Challenge, the goal is to exit the parking lot, complete three laps with correct traversal of all pillars, and return to the parking lot without touching the walls and in the shortest possible time. Using ultrasonic and IMU sensors, the robot first leaves the parking area and navigates section by section. At each corner, the robot positions itself at the back-center of the corner section, where the camera system captures an image of the area. During the traversal of each section, the robot maintains a specified threshold from the inner or outer wall according to the detected pillar color and the round direction. It then passes all pillars in sequence while regulating its motion to ensure stable wall following and smooth transitions. After all pillars in a section are traversed, the robot moves to the back-center of the next corner and repeats the same process for the following sections. In the starting section containing the parking lots, the offset is shifted closer to the track center, preventing the robot from touching the parking borders.

### Pillar Detection

The following `pillar_detection_client` function implements the main algorithm for detecting the pillars and storing their data in global arrays. 

```python
def pillar_detection_client():
    """
    Call the 'pillar_detection' ROS service to detect pillars.
    Based on first section or later logic, filter or store the pillars list
    into pillars_array for further navigation decisions.
    """
    global check_pillar, first_section, first_section_color, pillars_array, far_cw_pillar
    if first_section == 0:
        # after the first section, wait and call the service
        rospy.wait_for_service('pillar_detection')
        try:
            pillar_detection = rospy.ServiceProxy('pillar_detection', PillarDetection)
            request = PillarDetectionRequest()
            response = pillar_detection(request)
            temp = []
            n = len(response.pillars)
            print(f'n: {n}')
            # Some filtering logic: if too many pillars or disparity is large or with background distance, prune
            if (n > 2) or ((response.pillars[n-1].distance - response.pillars[0].distance > value)
                           and response.pillars[0].distance + dists[b] < 90) \
               or (response.pillars[0].distance + dists[b] >= 90 and n == 2):
                m = 1 if n == 2 else 2
                for i in range(m):
                    temp.append(response.pillars[i])
            else:
                for i in range(n):
                    temp.append(response.pillars[i])
            pillars_array.append(temp)
        except rospy.ServiceException as e:
            print(f"Service call failed: {e}")
    else:
        # first section: simpler logic to decide if a pillar is present
        pillar_detection = rospy.ServiceProxy('pillar_detection', PillarDetection)
        request = PillarDetectionRequest()
        response = pillar_detection(request)
        # threshold distance depending on dir1
        di = 40 if dir1 == -1 else 90 
        if len(response.pillars) > 0:
            # if pillar is “far enough”, set check_pillar = 0 else 1
            check_pillar = 0 if response.pillars[0].distance > di else 1
            if di == 90 and response.pillars[0].distance > 40:
                far_cw_pillar = 1
            first_section = 0
            # record the color of the first pillar if in range
            first_section_color = response.pillars[0].color if response.pillars[0].distance < di else -1
        else:
            check_pillar = 0
            first_section = 0
        pillars_array.append([])
```

### Pillar Avoidance Strategy

**Threshold Selection:** Choose inner/outer wall bias based on pillar colors:

- Red pillars → Outer wall preference
- Green pillars → Inner wall preference
  **Sequential Navigation:** Clear pillars one by one using ultrasonic feedback

The `pid_control` function maintains the desired thresholds while passing pillars.

```python
def pid_control(kp1=0.5, kp2=-0.75, kd2=0, speed=max_speed,
                threshold_dist=15, threshold_angle=0,
                sens=outer, dists=[15,15,15,15]):
    """
    PID-like control combining angular and distance corrections.
    - sens: which sensor (outer, inner, etc.) to use for lateral distance error.
    - threshold_dist: target distance from that sensor side.
    - threshold_angle: desired yaw offset.
    - kp1 handles angular (yaw) error, kp2 handles distance error.
    Sets steering by converting corr → steering angle, and moves DC motor.
    """
    global prev_dist_err, steering, dist_err
    # compute lateral distance error (positive or negative depending on side)
    dist_err = (dists[sens] - threshold_dist) if sens == l else (-dists[sens] + threshold_dist)
    
    angle_err = yaw + float(dir1 * sec * 90) - threshold_angle
    # if yaw error too large, we suppress correction gain
    if abs(yaw + float(dir1 * sec * 90)) > 60:
        kp2 = 0
    
    corr = (kp1 * (angle_err)
            + (kp2 * (dist_err) + kd2 * (dist_err - prev_dist_err)) * (abs(dist_err) > 0))
    # bound corr
    if corr > 25:
        corr = 25
    elif corr < -25:
        corr = -25
    steering = steering_angle(corr)
    move_dc(speed, pi_pwm1, pi_pwm2)
```

<p align="center">
  case
  &nbsp;&nbsp;
  case B
  </p>

### Performing parallel parking

After completing all sections, the robot performs a parallel-parking maneuver in the designated spot using the final distance to the outer wall and the robot angle as references. Once properly aligned, the robot comes to a full stop, marking the end of the round. 

The `parking` function imitates the real-world cars' movements to perform parallel parking.

```python
def parking():
    """
    The final parking maneuver. Reverse, steer, and align in the parking slot.
    """
    global steering
    steering = min_steering * (dir1 == -1) + max_steering * (dir1 == 1)
    while abs(yaw + float(dir1 * sec * 90)) < 40:
        move_dc(-60, pi_pwm1, pi_pwm2)
    steering = 0
    stop_dc(0, 0.3)
    while dists[inner] < 68:
        move_dc(-60, pi_pwm1, pi_pwm2)
    steering = max_steering * (dir1 == -1) + min_steering * (dir1 == 1)
    stop_dc(0, 0.3)
    while dists[outer] > 5 and dists[b] > 10:
        pid_control(kp1=-3, kp2=0, kd2=0, speed=-60, threshold_dist=3, threshold_angle=0)
    d = dists[outer]
    while dists[inner] < 82 or abs(yaw + float(dir1 * sec * 90)) > 3:
        prevTime = time.time()
        while dists[f] < 15 and (dists[inner] < 82 or abs(yaw + float(dir1 * sec * 90)) > 3) and time.time() - prevTime < 0.25:
            move_dc(-50, pi_pwm1, pi_pwm2)
            steering = min_steering * (dir1 == -1) + max_steering * (dir1 == 1)
        prevTime = time.time()
        while dists[f] < 15 and (dists[inner] < 82 or abs(yaw + float(dir1 * sec * 90)) > 3):
            move_dc(-50, pi_pwm1, pi_pwm2)
            steering = max_steering * (dir1 == -1) + min_steering * (dir1 == 1)
        thresh = dists[inner] + 0.5
        dis = copy.deepcopy(dists)
        while dists[f] > 7 and (dists[inner] < 82 or abs(yaw + float(dir1 * sec * 90)) > 3):
            pid_control(kp1=2, kp2=0, speed=50)
            dis = copy.deepcopy(dists)
    while dists[f] < 12:
        pid_control(kp1=-1.5, kp2=0, kd2=0, speed=-50, threshold_angle=0)
        flag = 1
    while dists[f] > 12:
        pid_control(kp1=1.5, kp2=0, kd2=0, speed=50, threshold_angle=0)
        flag = -1
    stop_dc(flag * 50, 0.1)
    steering = 0
```
  
## Problems We Encountered 

### Wave Interference

**Issue:** Interference of ultrasonic sensors when operating simultaneously
**Solution:** Sequential sensor activation - alternating between opposite sides (R1+L2, then R2+L1, then F+B)

### Mechanical Limitations

**Issue:** Small turn angles and wheel slipping without a differential
**Solution:** Implemented a Lego differential gear system for smooth turning

### Camera Flickering

**Issue:** Brightness fluctuations in video stream
**Solution:** Manual shutter speed control: `picam2.set_controls({"ExposureTime": shutter_speed})`

### Real-Time Performance

**Issue:** Synchronizing multiple sensor streams
**Solution:** ROS middleware with timestamped messages and configurable update rates

# Suggestions and Future Modifications 

## Mobility Management

### Mechanical Upgrades

- **Metal Differential:** Replace Lego components with metal differential and axles
- **Robust Coupling:** Metal motor-to-axle adapter for improved reliability
- **Enhanced Bearings:** Low-friction bearings for smoother operation

## Power and Sense Management

### Sensor Improvements

- **Direct IMU Integration:** Connect BNO086 directly to Raspberry Pi I2C
- **ToF Sensors:** Upgrade from ultrasonic to VL53L1X Time-of-Flight sensors
- **LiDAR Integration:** Consider RPLIDAR A1 for 360° obstacle detection

### Power Management

- **Battery Management System:** Implement BMS for cell monitoring and protection
- **Custom PCB:** Design an integrated board for robust connections and clean wiring
- **Thermal Management:** Enhanced cooling for sustained operation

## Computer Vision

### Hardware Upgrade

- **Depth Camera:** Intel RealSense D435 for accurate distance measurement
- **Wider FOV:** Improved peripheral vision for obstacle detection

### Software Optimization

- **Persistent Mapping:** Cache pillar configurations after first lap
- **Path Optimization:** Direct section-to-section navigation on subsequent laps
- **Advanced Algorithms:** Machine learning for improved pillar classification

## System Integration

### Performance Enhancements

- **Real-Time OS:** Consider RT kernel for deterministic timing
- **Sensor Fusion:** Advanced Kalman filtering for state estimation
- **Predictive Control:** Model predictive control for optimal path planning

# Resources 

## Technical Documentation

- [WRO 2025 Future Engineers Rules](https://wro-association.org/wp-content/uploads/WRO-2025-Future-Engineers-Self-Driving-Cars-General-Rules.pdf)
- [ROS Noetic Documentation](http://wiki.ros.org/noetic)
- [OpenCV HSV Color Space](https://docs.opencv.org/3.4/da/d97/tutorial_threshold_inRange.html)

## Component Datasheets

- [Raspberry Pi 4 Model B](https://www.raspberrypi.org/products/raspberry-pi-4-model-b/)
- [ESP32-WROOM-32E](https://www.espressif.com/sites/default/files/documentation/esp32-wroom-32e_esp32-wroom-32ue_datasheet_en.pdf)
- [BNO086 IMU](https://cdn.sparkfun.com/assets/1/3/4/5/9/BNO086_Datasheet.pdf)
- [DRV8871 Motor Driver](https://www.ti.com/lit/ds/symlink/drv8871.pdf)

## Open Source Libraries

- [rosserial](http://wiki.ros.org/rosserial) - Arduino/ESP32 to ROS bridge
- [OpenCV](https://opencv.org/) - Computer vision processing
- [SH-2 Reference Manual](https://www.ceva-dsp.com/wp-content/uploads/2019/10/BNO080_085-Datasheet.pdf)

---

## Copyright

```
MIT License

Permission is hereby granted, free of charge, to any person obtaining a copy of this software and associated documentation files (the "Software"), to deal in the Software without restriction, including without limitation the rights to use, copy, modify, merge, publish, distribute, sublicense, and/or sell copies of the Software, and to permit persons to whom the Software is furnished to do so, subject to the following conditions:

The above copyright notice and this permission notice shall be included in all copies or substantial portions of the Software.

THE SOFTWARE IS PROVIDED "AS IS", WITHOUT WARRANTY OF ANY KIND, EXPRESS OR IMPLIED, INCLUDING BUT NOT LIMITED TO THE WARRANTIES OF MERCHANTABILITY, FITNESS FOR A PARTICULAR PURPOSE AND NONINFRINGEMENT. IN NO EVENT SHALL THE AUTHORS OR COPYRIGHT HOLDERS BE LIABLE FOR ANY CLAIM, DAMAGES OR OTHER LIABILITY, WHETHER IN AN ACTION OF CONTRACT, TORT OR OTHERWISE, ARISING FROM, OUT OF OR IN CONNECTION WITH THE SOFTWARE OR THE USE OR OTHER DEALINGS IN THE SOFTWARE.

© 2025 SQ-391 Team
```

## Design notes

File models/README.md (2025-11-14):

# Models

Mechanical design files for the **WRO Future Engineers 2025** robot.  
This directory contains laser-cut plates (DXF), 3D-printed parts (STL), and small assembly helpers.

> ▶️ **Building Instructions (YouTube):**  
> [Watch the full assembly video](https://youtu.be/wnCx0N_8Aeo)  

---

## Folder map

```
models/
├── 3d-printed-parts/
│   ├── cameraholder.STL
│   ├── cameraholder2.STL
│   ├── dc holder.STL
│   ├── dc holder2.STL
│   ├── urm_holder_hor.STL
│   ├── urm_holder_ver.STL
│   └── wall.STL
├── CNC-cut-parts/
│   ├── additional.DXF
│   ├── chassis.DXF
│   ├── cooplerlego (6).DXF
│   ├── cooplermotor (6).DXF
│   ├── hexaforrasprebrry (8).DXF
│   ├── layer2.DXF
│   ├── powerboardholder2.DXF
│   └── powerboardholderr.DXF
└── assembly-parts/
```

> **Units:** all drawings are in millimeters (mm).  
> **Scale:** export/print at 1:1 scale.  
> **Default quantity:** `1×` each unless otherwise noted in the filename.

---

## 3D-printed parts

| File | Purpose | Notes / Print hints |
|---|---|---|
| `cameraholder.STL` | Primary camera mount. | Print with the flat face on the bed; consider 3–4 perimeters for screw stiffness. |
| `cameraholder2.STL` | Alternate/extended camera mount. | Use if you need different tilt/offset; same print settings as above. |
| `dc holder.STL` | DC motor holder (variant A). | PETG recommended near motor; 35–40% infill. |
| `dc holder2.STL` | DC motor holder (variant B). | Choose the one that matches your motor body/holes. |
| `urm_holder_hor.STL` | Ultrasonic sensor holder – horizontal. | Mounts URM sensor in a horizontal orientation. |
| `urm_holder_ver.STL` | Ultrasonic sensor holder – vertical. |  Mounts URM sensor in a vertial orientation. |
| `wall.STL` | Spacer/brace between plates. | Print upright; increase walls/perimeters for stiffness. |

**General print recommendations**
- **Material:** PETG (preferred) or PLA.  
- **Layer height:** 0.2 mm.  
- **Perimeters & infill:** 3–4 perimeters, 25–40% infill (Gyroid/Cubic).  
- **Fasteners:** designed around typical **M3** screws + heat-set inserts where applicable.

---

## CNC / Laser-cut parts (DXF)

| File | Purpose | Notes |
|---|---|---|
| `chassis.DXF` | Lower/main plate of the two-layer chassis. | 
| `layer2.DXF` | Upper plate of the chassis. |
| `hexaforrasprebrry (8).DXF` | Hex spacer/adapter for Raspberry Pi mounting (×8 implied). |
| `powerboardholder2.DXF` | Power board mount – v2. |
| `powerboardholderr.DXF` | Power board mount – alt. | 
| `cooplerlego (6).DXF` | LEGO axle coupler outline (×6 implied). | 
| `cooplermotor (6).DXF` | Motor shaft coupler outline (×6 implied). | 
| `additional.DXF` | Extra small brackets/spacers. | 

**Cutting recommendations**
- **Material:** 3–4 mm clear acrylic (PMMA) for rigidity/weight balance.
- **Kerf:** compensate ~0.10–0.20 mm (depends on your cutter).  
- **Holes:** pilot undersized if threads will be tapped; otherwise size for M3 clearance.  

---

## Quick build flow

1. **Cut** `CNC-cut-parts/*.DXF` with 3–4 mm sheet (see kerf note).  
2. **Print** required `3d-printed-parts/*.STL` 
3. **Dry fit** plates + `wall.STL` spacers with M3 hardware.  
4. **Install** drivetrain (DC motor in `dc holder*`, coupler(s), axle/wheels).  
5. **Mount** electronics (Raspberry Pi/ESP32, power board using the holder DXFs).  
6. **Attach** sensors (URM holders; camera holder variant that fits your lens/angle).  
7. **Cable manage** and verify clearances through full steering/suspension travel.

> Detailed steps are demonstrated in the **YouTube build video** linked above.

---

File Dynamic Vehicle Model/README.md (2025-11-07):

# Bicycle Kinematic Model and PID Control for Autonomous Navigation

This folder provides a comprehensive explanation of the bicycle kinematic model and how we use it in our robot.

## Table of Contents

- [Introduction](#introduction)
- [Bicycle Kinematic Model](#bicycle-kinematic-model)
  - [Model Description](#model-description)
  - [Kinematic Equations](#kinematic-equations)
  - [Ackermann Steering Geometry](#ackermann-steering-geometry)
- [Application to SQ-391 Robot](#application-to-sq-391-robot)
- [PID Control for Path Tracking](#pid-control-for-path-tracking)
  - [Error Functions](#error-functions)
  - [Control Law](#control-law)
  - [Parameter Tuning](#parameter-tuning)
- [Python Simulation](#python-simulation)
- [References](#references)

---

## Introduction

The **bicycle kinematic model** is a widely used simplified representation of car-like vehicle dynamics in robotics and autonomous vehicle research [[1](#ref1), [2](#ref2)]. Instead of modeling all four wheels of a vehicle, the bicycle model approximates the vehicle with two wheels: one at the front (steerable) and one at the rear (fixed orientation). This simplification significantly reduces computational complexity while maintaining sufficient accuracy for path planning and control applications [[3](#ref3)].

Our SQ-391 robot employs an Ackermann steering mechanism with a differential drive system, making it an ideal candidate for bicycle model-based control strategies. This folder explores the mathematical foundations of the bicycle model and demonstrates how PID control can be used for robust path tracking.

---

## Bicycle Kinematic Model

### Model Description

The bicycle model represents a vehicle with:
- **Wheelbase (L)**: Distance between front and rear axles
- **Steering angle (δ)**: Angle of the front wheel relative to vehicle orientation
- **Vehicle pose**: Position (x, y) and heading angle (θ) at the center of the rear axle

The model assumes:
- No wheel slip (pure rolling motion)
- Planar motion (no vertical dynamics)
- Low-speed kinematics (lateral forces negligible)
- Point contact between wheels and ground

### Kinematic Equations

The bicycle kinematic model is described by the following differential equations [[1](#ref1)]:

```
ẋ = v cos(θ)
ẏ = v sin(θ)
θ̇ = (v/L) tan(δ)
```

Where:
- `(x, y)` = Position of the rear axle in global coordinates
- `θ` = Heading angle (yaw) of the vehicle
- `v` = Linear velocity at the rear axle
- `δ` = Steering angle of the front wheel
- `L` = Wheelbase length

**Discrete-time update equations** (for simulation with time step Δt):

```
x(k+1) = x(k) + v·cos(θ(k))·Δt
y(k+1) = y(k) + v·sin(θ(k))·Δt
θ(k+1) = θ(k) + (v/L)·tan(δ(k))·Δt
```

### Ackermann Steering Geometry

The Ackermann steering mechanism ensures that all wheels follow concentric circular paths during turns, minimizing tire slip [[4](#ref4)]. The fundamental Ackermann steering equation relates the inner and outer wheel angles:

```
cot(δ_outer) - cot(δ_inner) = w/L
```

Where:
- `w` = Track width (lateral distance between left and right wheels)
- `L` = Wheelbase
- `δ_inner` = Steering angle of inner wheel (sharper)
- `δ_outer` = Steering angle of outer wheel (gentler)

**Turning radius** from the instantaneous center of curvature (ICC):

```
R = L / tan(δ)
```

Where `δ` is the equivalent bicycle model steering angle (approximated as the average of the front wheel angles).

**Ackermann percentage** in practical implementations [[4](#ref4)]:

Most real vehicles achieve 80-100% Ackermann geometry due to mechanical constraints. The SQ-391 robot uses a servo-actuated Ackermann linkage with a percentage that can be calibrated through the mechanical design.

---

## Application to SQ-391 Robot

Our robot incorporates several design elements that align with the bicycle kinematic model:

### Mechanical Design
- **Wheelbase (L)**: Distance between front Ackermann steering assembly and rear differential
- **Ackermann Steering**: Ensures proper turning geometry with minimal tire scrub
- **Differential Drive**: Allows rear wheels to rotate at different speeds during turns
- **Servo Control**: MG996R servo provides precise steering angle control

### Sensor Integration
- **IMU (BNO086)**: Provides heading angle `θ` and angular velocity `θ̇`
- **Ultrasonic Sensors (URM09)**: Measure lateral distances for error calculation
- **Camera Module**: Detects track boundaries and obstacles

### Control Architecture
The robot uses ROS Noetic with the following control structure:
1. **Localization**: IMU provides orientation; odometry estimates position
2. **Path Planning**: Generate reference trajectory based on track geometry
3. **Control**: PID controller computes steering commands based on error signals

---

## PID Control for Path Tracking

### Error Functions

Our robot employs a **dual-error PID controller** that combines heading error and lateral position error [[5](#ref5), [6](#ref6)]:

**1. Heading Error (Angle Error)**

```
e_θ(t) = wrap(θ_ref - θ(t))
```

Where:
- `θ_ref` = Desired heading angle (e.g., tangent to the path)
- `θ(t)` = Current heading from IMU
- `wrap()` = Function to normalize angle to [-π, π]

**2. Lateral Distance Error**

```
e_d(t) = d_right(t) - d_left(t)
```

Where:
- `d_right(t)` = Distance to right wall (from ultrasonic sensors)
- `d_left(t)` = Distance to left wall (from ultrasonic sensors)

This error represents the lateral deviation from the centerline. When `e_d > 0`, the robot is closer to the left wall; when `e_d < 0`, it's closer to the right wall.

### Control Law

The composite steering correction is calculated as [[7](#ref7)]:

```
corr(t) = kp1 · e_θ(t) + kp2 · e_d(t)
```

Where:
- `kp1` = Proportional gain for heading error (≈ 0.5)
- `kp2` = Proportional gain for lateral distance error (≈ -0.75)

The negative sign on `kp2` ensures proper corrective action: when `e_d > 0` (robot too far left), a negative correction steers right.

**Steering angle command**:

```
δ_cmd(t) = δ_nominal + corr(t)
```

Where `δ_nominal` is the feedforward steering angle for the desired path curvature.

### Parameter Tuning

**Tuning Guidelines** [[8](#ref8), [9](#ref9)]:

1. **kp1 (Heading Error Gain)**:
   - Start with `kp1 = 0.3` and increase gradually
   - Too low: Slow response to heading errors, poor corner entry
   - Too high: Oscillations around the path, overshoot
   - Optimal range: `0.4 - 0.6` for WRO-sized tracks

2. **kp2 (Lateral Error Gain)**:
   - Start with `kp2 = -0.5` and adjust magnitude
   - Too low magnitude: Slow lateral correction, wall proximity
   - Too high magnitude: Oscillations, "zigzag" motion
   - Optimal range: `-0.6 to -0.9` depending on sensor noise

**Tuning Process**:
1. Set both gains to zero and test open-loop steering
2. Increase `kp1` until heading tracking is acceptable
3. Add `kp2` gradually to center the robot on the track
4. Fine-tune both parameters simultaneously
5. Test at different speeds and track sections

**Advanced Considerations**:
- Add derivative terms (`kd1`, `kd2`) to reduce oscillations [[10](#ref10)]
- Implement gain scheduling: adjust gains based on velocity
- Use integral terms for steady-state error elimination (e.g., dealing with sensor bias)

---

## Python Simulation

The folder includes a complete Python simulation that demonstrates:

1. **Bicycle Model Dynamics**: Numerical integration of kinematic equations
2. **PID Controller**: Dual-error control law implementation
3. **Parameter Tuning Visualization**: Interactive plots showing effect of gain variations
4. **Path Tracking Performance**: Metrics including cross-track error, heading error, and control effort

See `pid_tuning_simulation.py` for the full implementation.

**Key Features**:
- Configurable track geometries (straight, circular, S-curve)
- Real-time visualization of robot trajectory
- Parameter sensitivity analysis
- Performance metrics calculation

**Simulation Results**:<br>

The following figures illustrate the bicycle model PID control and the difference between four different sets of values.
<p align="center">
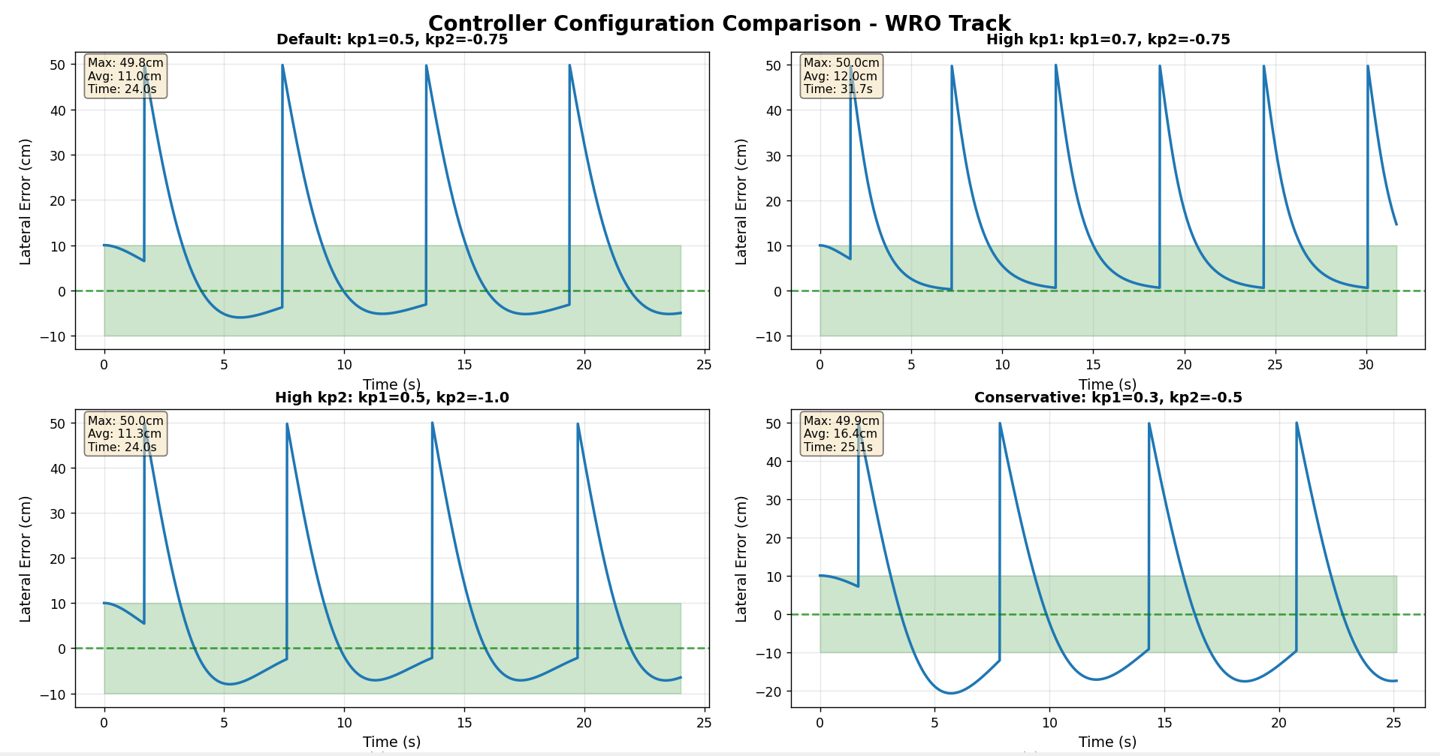
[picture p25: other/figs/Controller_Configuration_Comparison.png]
Controller_Configuration_Comparison
  
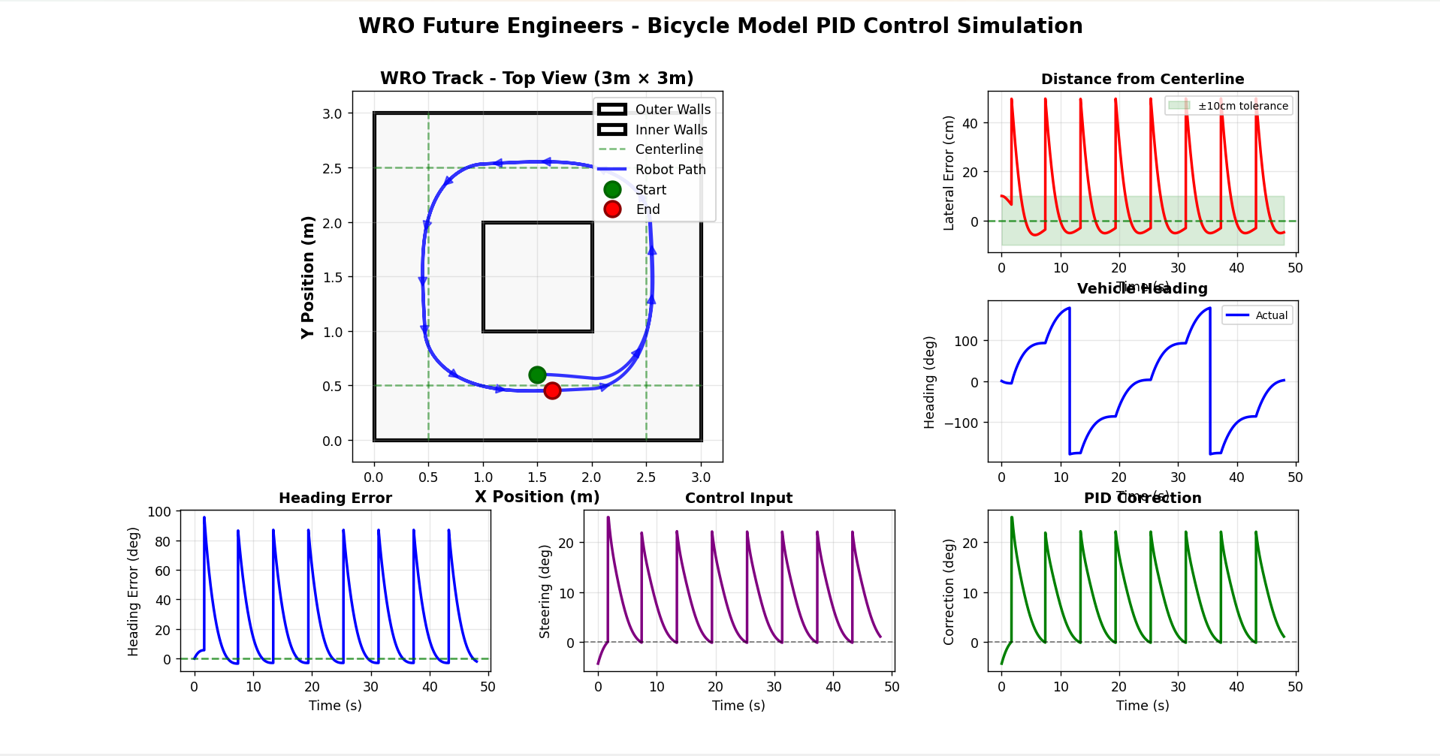
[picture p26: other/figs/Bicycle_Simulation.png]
Bicycle_Simulation
  
</p>
---

## References

[1] Dergipark (2022). "Trajectory tracking performance comparison of kinematic bicycle model with LQR and Lyapunov based controllers." *Uludağ Üniversitesi Mühendislik Fakültesi Dergisi*. Available: http://dergipark.org.tr/en/doi/10.55974/utbd.1130198

[2] IEEE (2020). "Implementation of Kinematics Bicycle Model for Vehicle Localization using Android Sensors." *2020 IEEE 10th International Conference on System Engineering and Technology*. doi: 10.1109/ICSET51301.2020.9232453

[3] MATLAB (2024). "Bicycle Kinematic Model - Compute car-like vehicle motion." *MathWorks Robotics System Toolbox Documentation*. Available: https://de.mathworks.com/help/robotics/ref/bicyclekinematicmodel.html

[4] RAW Robotics (2024). "Introduction to Ackerman Steering." *RAW Robotics Knowledge Base*. Available: https://raw.org/book/kinematics/ackerman-steering/

[5] Azam, S. et al. (2020). "Dynamic Control System Design for Autonomous Car." *SCITEPRESS Digital Library*. Available: https://www.scitepress.org/Papers/2020/93929/93929.pdf

[6] MDPI Electronics (2023). "Evaluating the Performance of Fuzzy-PID Control for Lane Recognition and Lane-Keeping in Vehicle Simulations." *Electronics*, 12(3), 724. doi: 10.3390/electronics12030724

[7] Martínez-Valdez, A., Ramirez-Neria, M., & González-Sierra, J. (2024). "Quanser Self Driving Car Trajectory Tracking by employing a Bicycle's Model." *CDSR 2024 Proceedings*. Available: https://avestia.com/CDSR2024_Proceedings/files/paper/CDSR_136.pdf

[8] Journal of Robotics and Control (2021). "Lane Keeping Maneuvers Using Proportional Integral Derivative (PID) and Model Predictive Control (MPC)." *JRC*, 2(2), 78-82. Available: https://journal.umy.ac.id/index.php/jrc/article/view/8800

[9] SAE International (2020). "Autonomous Lane Change Control Using Proportional-Integral-Derivative Controller and Bicycle Model." *SAE Technical Paper* 2020-01-0215. doi: 10.4271/2020-01-0215

[10] IEEE (2023). "Trajectory Tracking and Lane-Keeping Assistance for Autonomous Systems Using PID and MPC Controllers." *2023 International Conference on Control, Automation and Diagnosis*. doi: 10.1109/ICCAD57653.2023.10200281

[11] Qiu, N., Huang, Y., & Lu, Z. (2023). "Bicycle Trajectory Control Based on Kinematic and Dynamical Models." *Academic Journal of Mathematical Sciences*, 4(1), 32-43. doi: 10.25236/AJMS.2023.040106

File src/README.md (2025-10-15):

# WRO Future Engineers 2025 — Main Robot Code

This folder contains all code developed for the **WRO Future Engineers 2025** competition.  
It includes both legacy (old) versions and the final version used in the official robot during the competition.

---

## 📂 Repository Structure

```
📁 Old Version main code/
    └── Legacy implementation of the main robot logic (pre-final version).

📁 Old Version test and calibration/
    └── Experimental scripts for testing and sensor calibration.

📁 main code/catkin_ws/
    ├── src/
    │   ├── obstacle_challenge/
    │   │   └── launch/
    │   │       └── obstacle_run.launch
    │   └── open_challenge/
    │       └── launch/
    │           └── open_run.launch
    └── (ROS workspace used in competition)
```

---

## 🧠 About the Versions

### 🔹 Old Versions
- **Old Version main code** and **Old Version test and calibration** contain early prototypes and test scripts.
- They were used for calibration, component verification, and initial behavior development.

### 🔹 Main Code (Used in Competition)
- Located under:  
  ```
  main code/catkin_ws/
  ```
- This is the **ROS workspace** that runs the robot’s final version, including all control, vision, and navigation nodes.
- It was the version deployed during the **official WRO Future Engineers 2025** competition.

---

## 🚀 How to Run

### 1️⃣ Obstacle Challenge
To launch the full robot system for the **Obstacle Challenge**, run:

```bash
roslaunch obstacle_challenge obstacle_run.launch
```

### 2️⃣ Open Challenge
To launch the full robot system for the **Open Challenge**, run:

```bash
roslaunch open_challenge open_run.launch
```

> 💡 Run these commands inside the ROS workspace:
> ```bash
> cd main\ code/catkin_ws
> source devel/setup.bash
> ```

---

## ⚙️ Notes
- Ensure all dependencies are installed before launching (e.g., sensor drivers, camera node, control node).
- The launch files automatically start all relevant nodes and parameters for each challenge.

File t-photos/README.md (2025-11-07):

# Team Photos — SQ-391 · WRO Future Engineers 2025

Welcome to our photo corner! This folder holds our official and fun team shots.  
Click the button below to view a short slideshow that introduces our team.

<p align="center">
  <!-- 🔗 Replace the URL below with your slideshow link -->
  <a href="[https://docs.google.com/presentation/d/ADD-YOUR-SLIDES-ID-HERE/preview](https://docs.google.com/presentation/d/e/2PACX-1vQpNTA1awUkYYcp_LHEwkgDRRj8A_0GwkxYaYQRbZjrQYXRy6JfjwHjPD9ibvG3qv4FdMDlAlZ3yHqX/pub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)" target="_blank">
    
  </a>
</p>

---

## Files

- Official.jpg – our official team photo  
- funny.jpg – a lighter, behind-the-scenes moment

---

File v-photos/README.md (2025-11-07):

# Vehicle Photos

This folder contains the six standard views of our competition vehicle. These images are used across the engineering journal, README files, and presentations.

**Quick link:** [Open the detailed image slideshow](https://docs.google.com/presentation/d/1M-tDa23ikNhaoEma-UXxTMJ4RwqUE-HI14jeB9-3Re8/edit?usp=sharing) — a Google Slides presentation with higher‑resolution views, callouts, and notes.

---

## Contents

- `front.jpg` — Front view of the vehicle  
- `back.jpg` — Rear view of the vehicle  
- `left.jpg` — Left‑side view  
- `right.jpg` — Right‑side view  
- `top.jpg` — Top view  
- `bottom.jpg` — Bottom/underbody view  
- `README.md` — This file

---

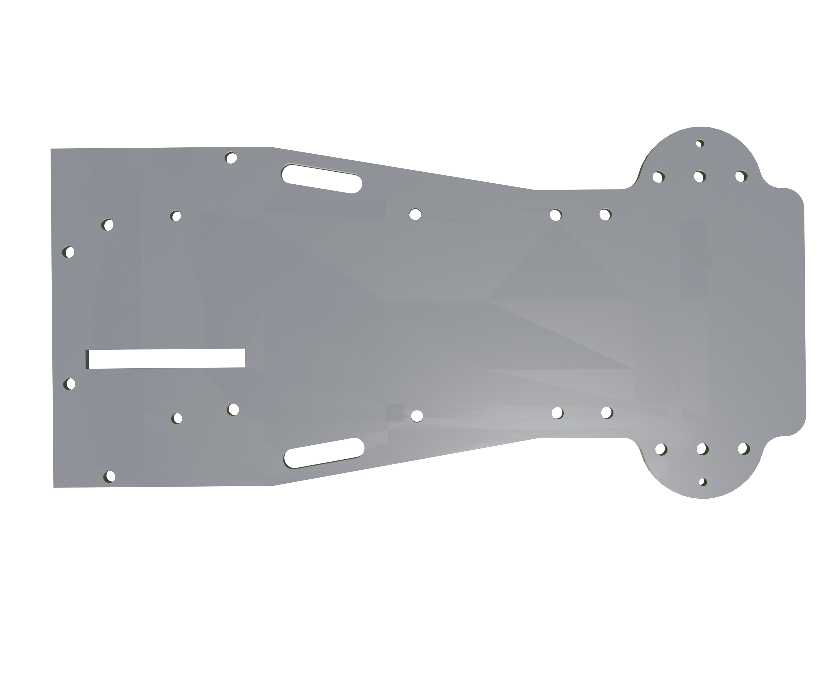
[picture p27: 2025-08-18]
other/figs/chassis.png

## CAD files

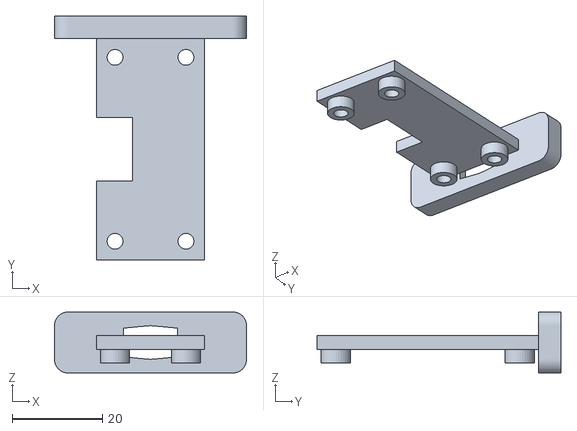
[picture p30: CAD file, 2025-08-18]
models/3d-printed-parts/urm_holder_ver.STL
42.5 x 54.0 x 13.5

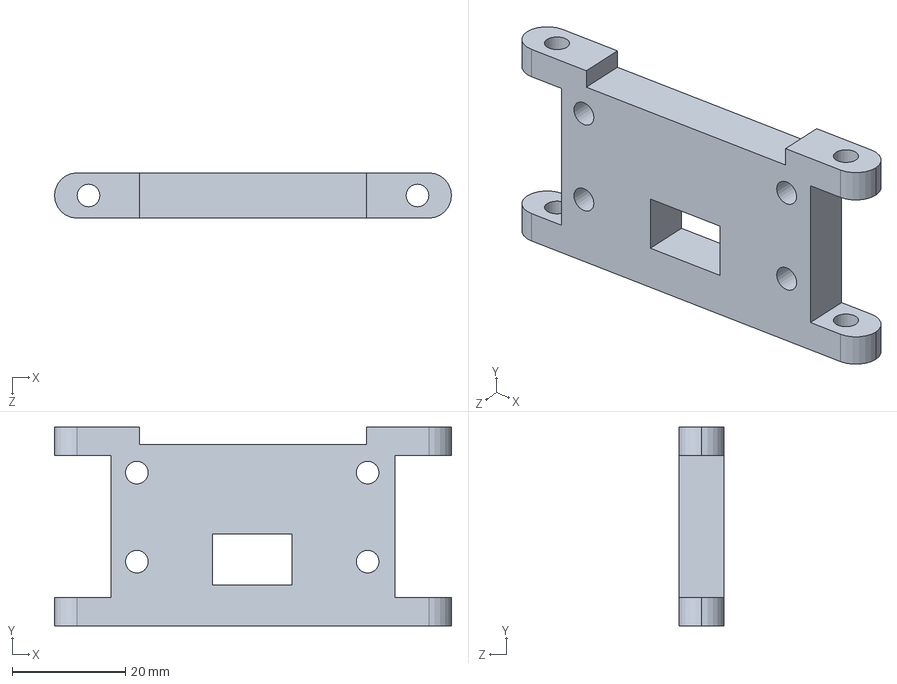
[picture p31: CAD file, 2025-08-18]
models/assembly-parts/wall.SLDPRT
70.0 x 35.0 x 8.00 mm

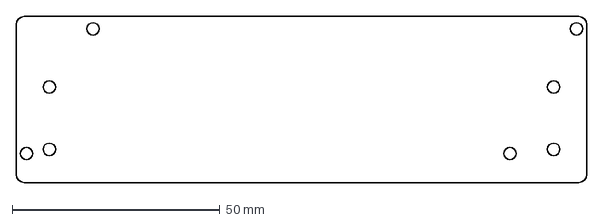
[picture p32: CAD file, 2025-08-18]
models/CNC-cut-parts/powerboardholderr.DXF
137.4 x 40.0 mm

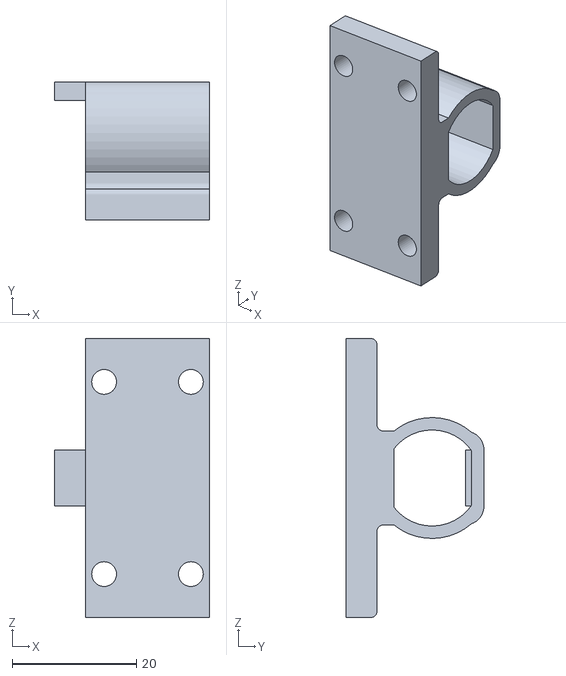
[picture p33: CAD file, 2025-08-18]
models/3d-printed-parts/dc holder2.STL
25.0 x 22.2 x 45.0

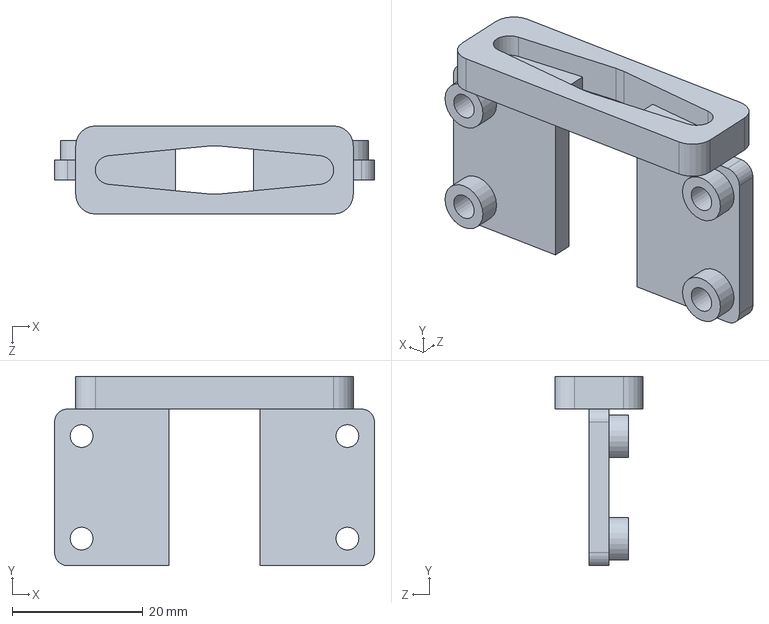
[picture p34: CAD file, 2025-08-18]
models/assembly-parts/urm_holder_hor.SLDPRT
49.0 x 29.0 x 13.5 mm

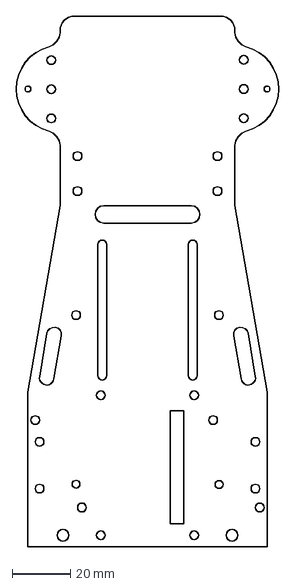
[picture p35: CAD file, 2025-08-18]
models/CNC-cut-parts/chassis.DXF
90.0 x 182.0 mm

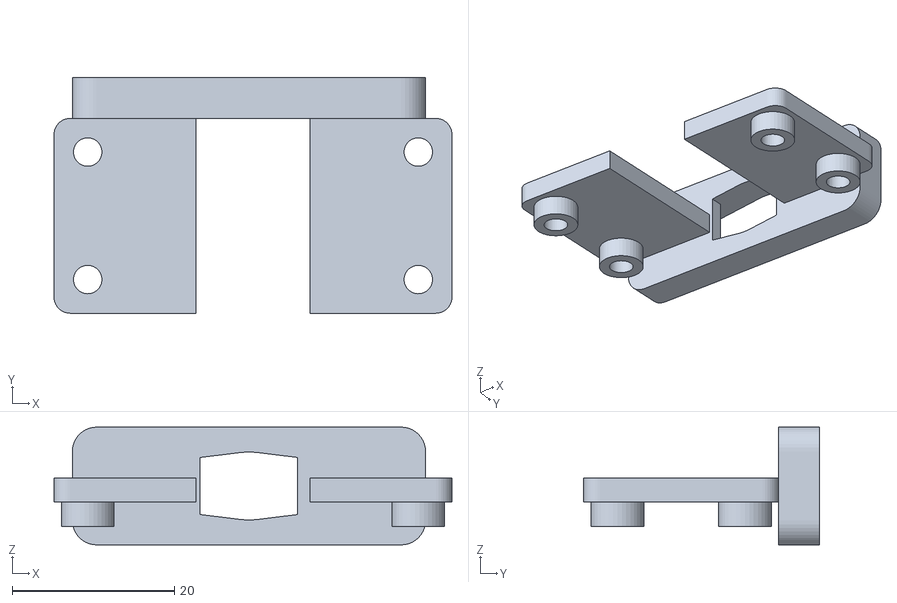
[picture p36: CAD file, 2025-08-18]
models/3d-printed-parts/urm_holder_hor.STL
49.0 x 29.0 x 14.5

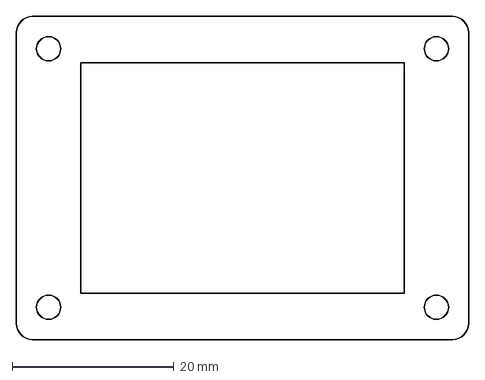
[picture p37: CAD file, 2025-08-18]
models/CNC-cut-parts/additional.DXF
56.0 x 40.0 mm

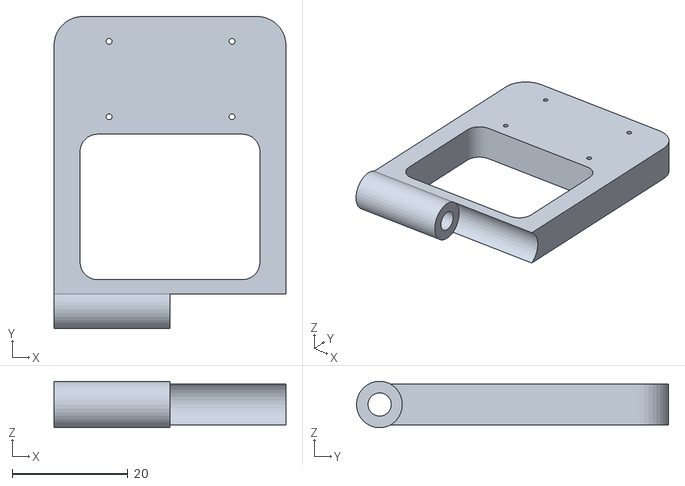
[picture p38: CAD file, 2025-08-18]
models/3d-printed-parts/cameraholder2.STL
40.0 x 53.8 x 8.00

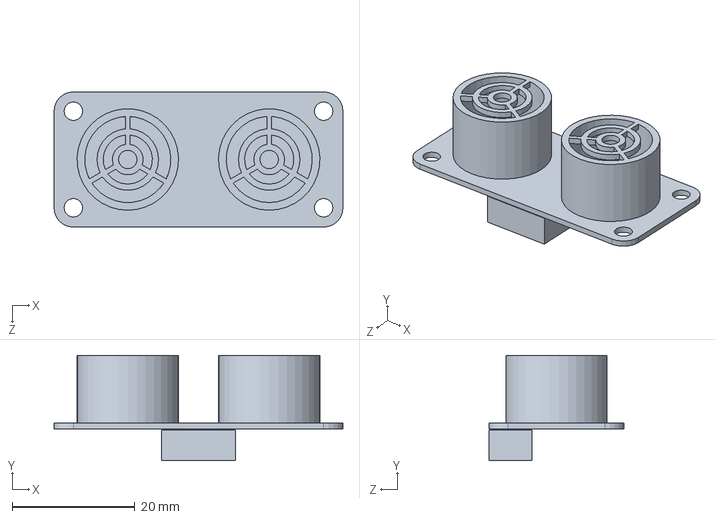
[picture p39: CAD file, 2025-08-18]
models/assembly-parts/URM09 ultrasonic sensor.SLDPRT
47.0 x 17.1 x 22.0 mm

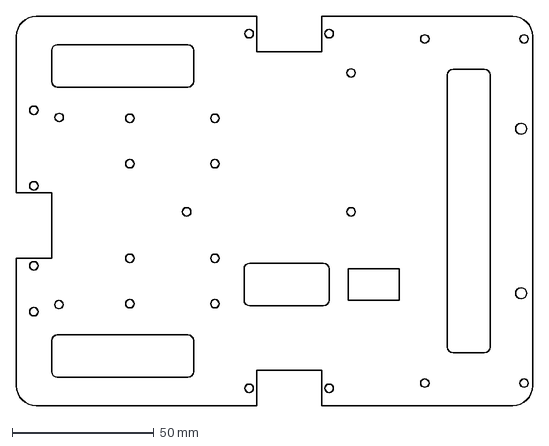
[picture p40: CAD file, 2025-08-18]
models/CNC-cut-parts/layer2.DXF
182.0 x 137.4 mm

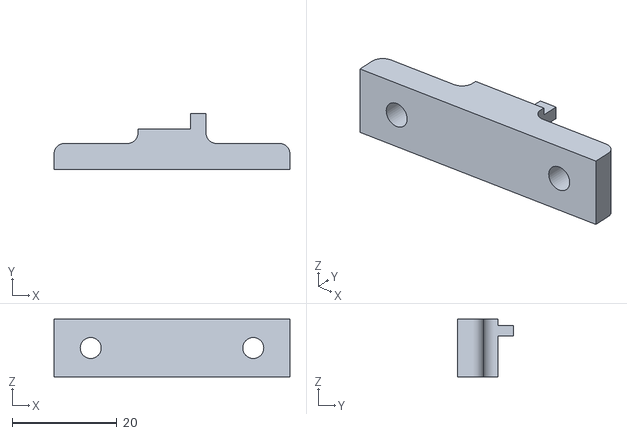
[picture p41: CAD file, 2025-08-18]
models/3d-printed-parts/dc holder.STL
45.0 x 10.7 x 11.0

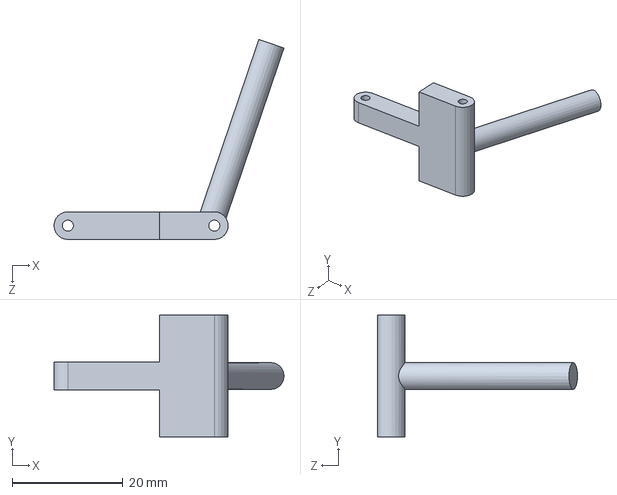
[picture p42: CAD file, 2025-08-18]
models/assembly-parts/side.SLDPRT
41.5 x 22.0 x 36.1 mm

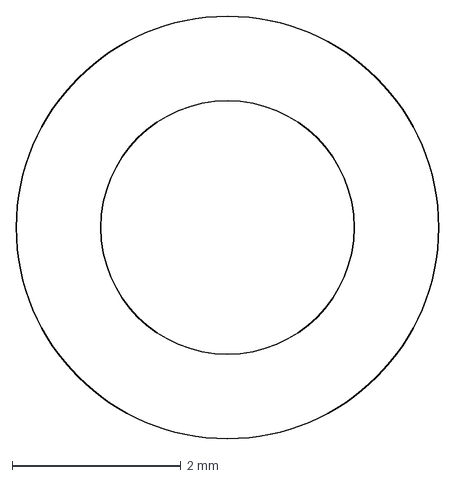
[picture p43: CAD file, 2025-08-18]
models/CNC-cut-parts/hexaforraspberry (8).DXF
5.00 x 5.00 mm

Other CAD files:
models/assembly-parts/urm_holder_ver.SLDPRT
models/3d-printed-parts/cameraholder.STL
models/assembly-parts/servo2.SLDPRT
models/CNC-cut-parts/cooplerlego (6).DXF
models/3d-printed-parts/wall.STL
models/CNC-cut-parts/cooplermotor (6).DXF
models/CNC-cut-parts/powerboardholder2.DXF
models/assembly-parts/(8258)_62821a-DkBluishGray v1.sldprt
models/assembly-parts/44294 Black Technic Axle 7 v1.sldprt
models/assembly-parts/56mm Wheel Normal Tread v1.SLDPRT
models/assembly-parts/Arduino Mega Case1.SLDPRT
models/assembly-parts/ArduinoMega.SLDPRT
models/assembly-parts/Core-DC-motor-jsumo.SLDPRT
models/assembly-parts/DRV8871_module.SLDPRT
models/assembly-parts/Lego Beam Fram 5x7 (64179).SLDPRT
models/assembly-parts/Pi camera module3.SLDPRT
models/assembly-parts/Servo Medium Horn.SLDPRT
models/assembly-parts/ServoHat for Raspberry.SLDPRT
models/assembly-parts/Tower Pro MG-995, Analog Servo.SLDPRT
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

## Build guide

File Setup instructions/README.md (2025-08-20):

## Software Setup 

Before using the robot, software should be configured first, you will need to install the following (Programs have been tested and configured with both Windows 10 and Windows 11 operating systems. In case of using another operating system, we strongly recommend using any available searching engine to search for the installation for the software by yourself).
We'll be using Raspberry Pi to run image processing code written in python programming language. Commands will be sent via Serial communication to arduino wich will control the motors.

### Raspberry Pi Preparation and Configuration
In this section, we will go through all the steps to prepare and configure your Raspberry Pi. After completing the steps, you will be able to access your Raspberry Pi remotely and control it.
#### Raspberry Pi Operating System 
There are a lot of OS systems for Raspberry Pi with different versions. You can choose any of them from [official site](https://www.raspberrypi.com/software/operating-systems/), but it is preferable to install the same version we installed since it is tested and it works fine ([download link](https://downloads.raspberrypi.com/raspios_full_arm64/images/raspios_full_arm64-2023-02-22/2023-02-21-raspios-bullseye-arm64-full.img.xz)).
#### Raspberry Pi Imager installation
You will be setting up Raspberry Pi OS on your Raspberry Pi using the Raspberry Pi Imager tool, it will allow you to flash the image onto a USB flash drive. The provided steps cover the installation process, initial configuration, and essential steps to get your Raspberry Pi up and running. 
Using the Raspberry Pi Imager tool to flash the Raspberry Pi OS image onto a USB flash drive offers a convenient and efficient way to set up your Raspberry Pi. The Imager simplifies the installation process by providing a user-friendly interface to select the operating system and target storage medium. With just a few clicks, you can download the official Raspberry Pi OS image and write it directly to the USB flash drive. This eliminates the need for manual installation and configuration, saving you time and effort.
- To install Raspberry Pi Imager, Visit the official Raspberry Pi website at https://www.raspberrypi.org/software/.
- Download the Raspberry Pi Imager tool suitable for your operating system (Windows, macOS, or Linux).
- Install Raspberry Pi Imager on your computer by following the provided instructions.
####Flashing the Raspberry Pi OS Image to USB
After downloading Raspberry Pi OS and installing the Imager, you can flash the OS Image to your USB (SD card can also be used):
 - Launch Raspberry Pi Imager on your machine.
 - In the Raspberry Pi Imager window, click on "Choose OS" button.
 - Click on "Use custom" option, then navigate to the directory of the OS that was previously downloaded.
 - Click on "Choose  Storage" option, in the file explorer window select your USB flash drive as the target storage medium.
 - The widnow should have the same configuration as the image below after choosing the flash drive and OS:
     
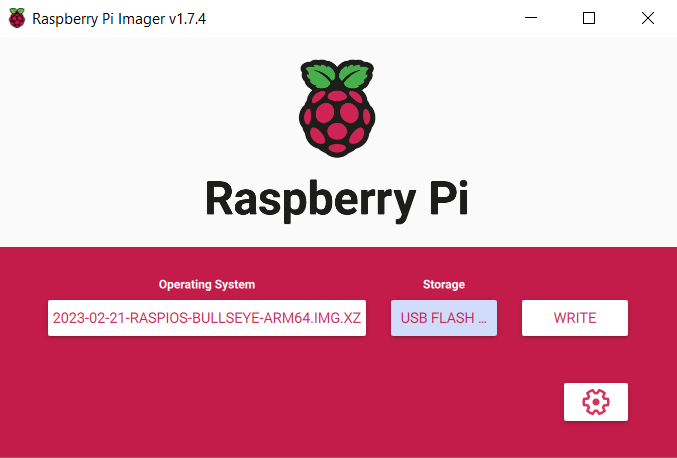
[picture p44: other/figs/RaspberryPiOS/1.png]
      <p align="center" Style="font-size:12px; color:grey; font-type:italic;"><i> Figure 1: RaspberryPi Imager </i></p>

 - Now click on the settings icon in the bottom right corner, you will need to enable the SSH option and choose a username and a password (This is necessary because you will use SSH to establish a connection between your device and Raspberry Pi, it will allow you to control the Raspberry Pi remotely).

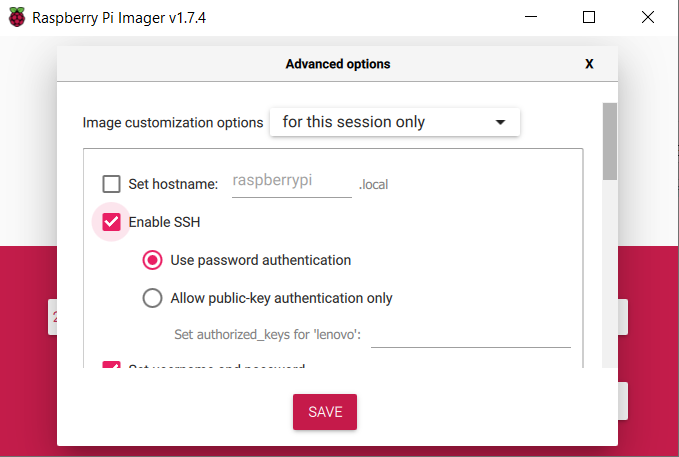
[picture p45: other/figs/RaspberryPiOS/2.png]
  <p align="center" Style="font-size:12px; color:grey; font-type:italic;"><i> Figure 2: RaspberryPi SSH connection enabling </i></p>
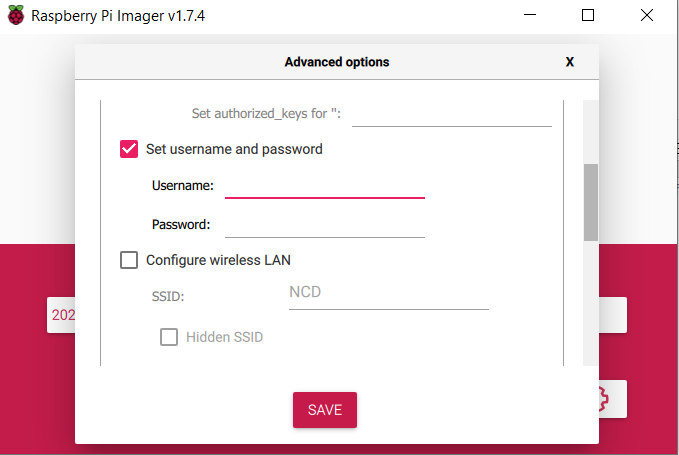
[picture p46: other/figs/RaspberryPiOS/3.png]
  <p align="center" Style="font-size:12px; color:grey; font-type:italic;"><i> Figure 3: RaspberryPi username and password </i></p>

- Next, you will need to enter the name of your network and its password, this will allow you to access the Raspberry pi directly and remotely.
   
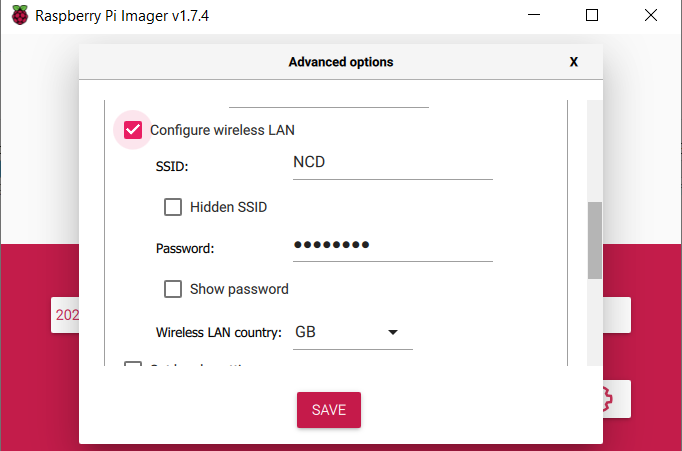
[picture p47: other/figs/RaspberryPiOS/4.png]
   <p align="center" Style="font-size:12px; color:grey; font-type:italic;"><i> Figure 4: RaspberryPi network configuration </i></p>

- Click on the "Write" button to start the flashing process. Raspberry Pi Imager will download the latest Raspberry Pi OS image and write it to the USB flash drive. This process may take several minutes, depending on your machine.
Once the flashing process is completed, Raspberry Pi Imager will display a success message.

### Raspberry Pi Remote Connection configuration
There three ways to control Raspberry Pi:
- Use a mouse, a monitor and a keyboard attached to your Raspberry Pi.
- Use ethernet cable attached to your machine and Raspberry Pi, and a virutal machine software.
- Connect both Raspberry Pi and your machine to the same network, and use a virtual machine software.

we will be using the third option since it is be a lot easier to control your Raspberry Pi remotely.
1. To control and access the Raspberry Pi, you will need a program to establish wireless connection. MobaXterm is the program that will allow you to establish this communication, which is based on SSH protocol.
 - Download the program from this [link]( https://mobaxterm.mobatek.net/download-home-edition.html), choose portable edition.
 - After succefully downloading the software, extract the contents of the downloaded file to a specified folder.
 - The program is ready to be used now, when launching it, a window like that will appear (it should be noted that both the raspberry pi and your device have to be connected to the same network):

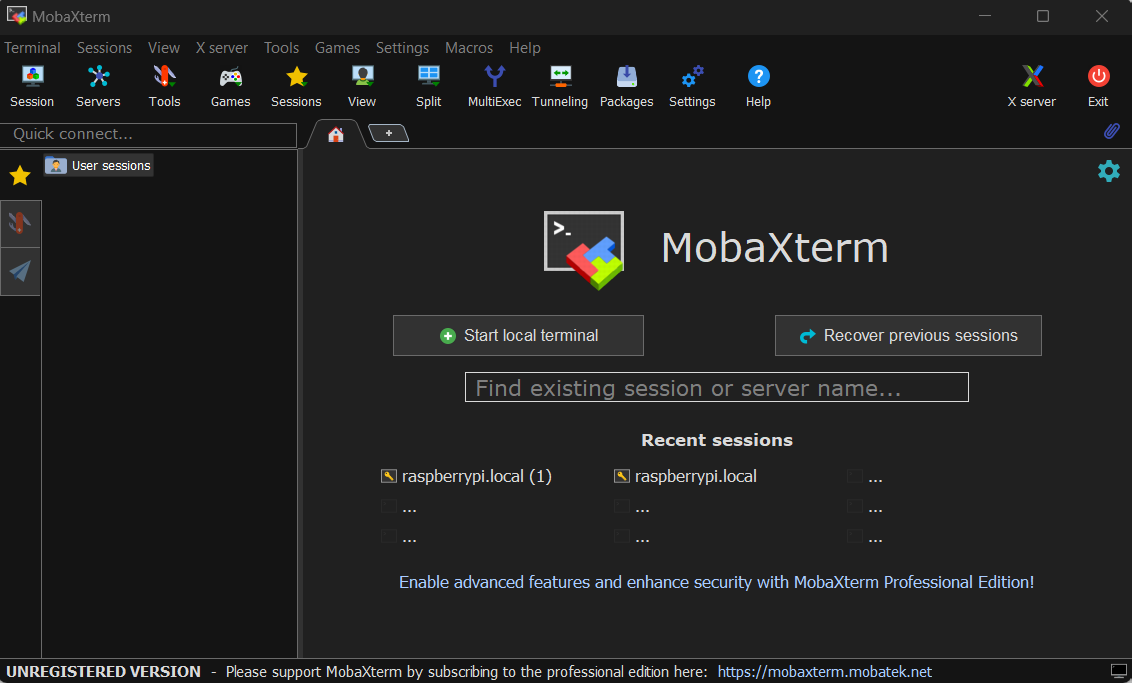
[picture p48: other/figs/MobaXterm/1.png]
MobaXterm
   <p align="center" Style="font-size:12px; color:grey; font-type:italic;"><i> Figure 5: MobaXterm Interface </i></p>

 - Choose Session tab in the top left corner:

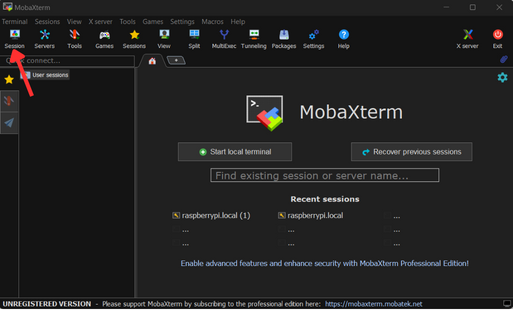
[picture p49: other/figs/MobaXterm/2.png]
Session Option
   <p align="center" Style="font-size:12px; color:grey; font-type:italic;"><i> Figure 6: Choosing new session </i></p>

 - A new window will appear that contains the settings of the new connection:

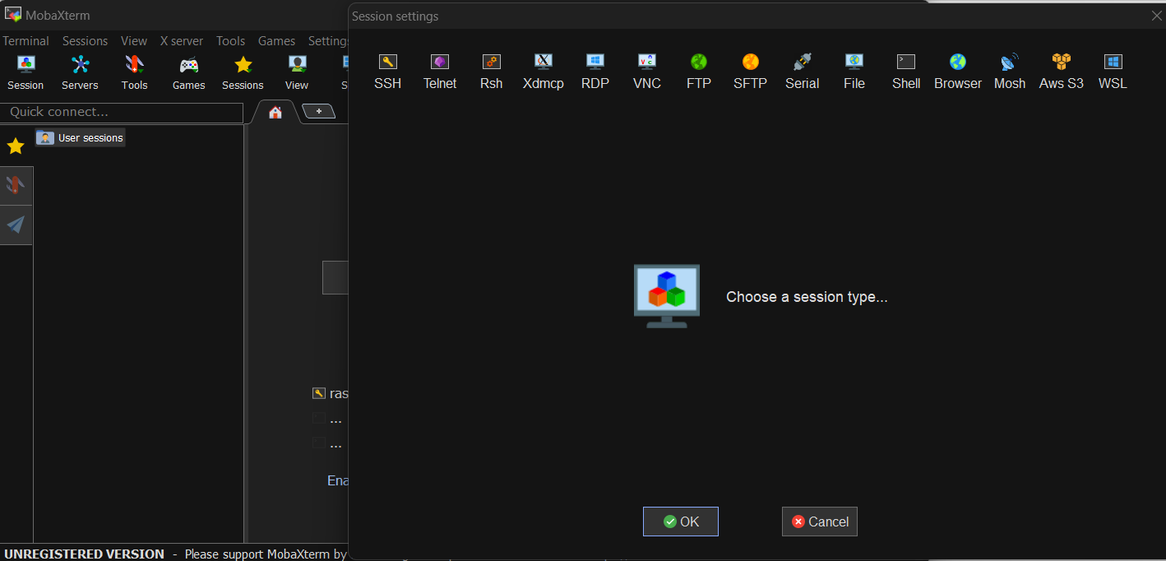
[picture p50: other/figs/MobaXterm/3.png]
Session window
   <p align="center" Style="font-size:12px; color:grey; font-type:italic;"><i> Figure 7: new session tab </i></p>

 - Click on the SSH icon, we will be using SSH in our work. SSH (Secure Shell) is a network protocol that provides a secure way to access and manage remote systems. It allows to establish a secure encrypted connection between local computer and a remote device, such as a Raspberry Pi in our case.Using SSH to access a Raspberry Pi offers several advantages, as it allows remote access to the Raspberry Pi's command-line interface, providing a convenient and efficient way to manage and configure the device. Through an SSH connection, commands can be executed, files can be transfered, perform system administration tasks without the need for physical access to the Raspberry Pi. Moreover, SSH is particularly useful for headless Raspberry Pi setups, where the device is not connected to a monitor or keyboard. In such cases, SSH enables remote administration, making it possible to configure and control the Raspberry Pi over the network from a different computer.

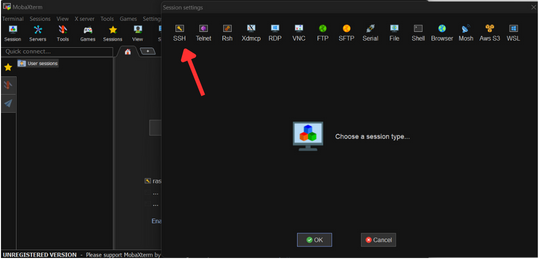
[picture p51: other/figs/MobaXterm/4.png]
SSH
   <p align="center" Style="font-size:12px; color:grey; font-type:italic;"><i> Figure 8: choosing SSH communication  </i></p>

- To establish a connection with the Raspberry Pi, remte host name will be needed, which will be raspberrypi.local (The IP of the Raspberry Pi can also be used, but the domain name raspberrypi.local will work fine). With current Configuration, all commands will be executed through the terminal, to make these operations easier, LXDE desktop will be used as GUI as in the image below:

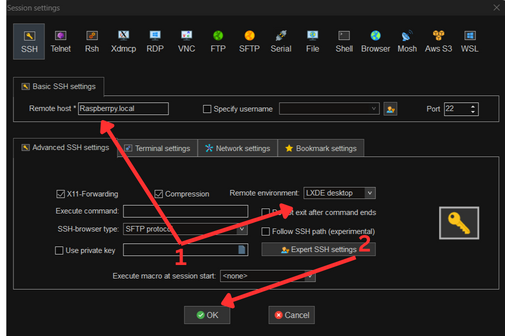
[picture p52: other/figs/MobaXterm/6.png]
   <p align="center" Style="font-size:12px; color:grey; font-type:italic;"><i> Figure 9: Remote Host and LXDE Desktop</i></p>

- Now the settings are ready, click ok and it will need the username and password that was set during the setup of the raspberrypi py operating system:

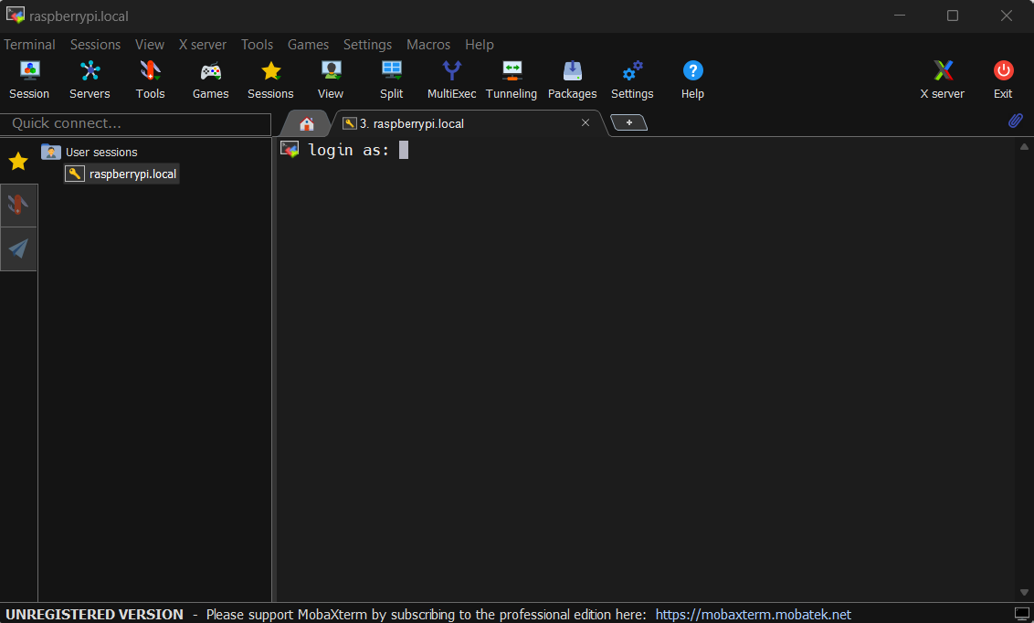
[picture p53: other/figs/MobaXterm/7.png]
   <p align="center" Style="font-size:12px; color:grey; font-type:italic;"><i> Figure 10:Login window </i></p>

- After applying the previous steps, connection is succefully established and Raspberry Pi is ready to be used remotely, a new LXDE desktop window will be opened, all subsequent work will be done here:
  
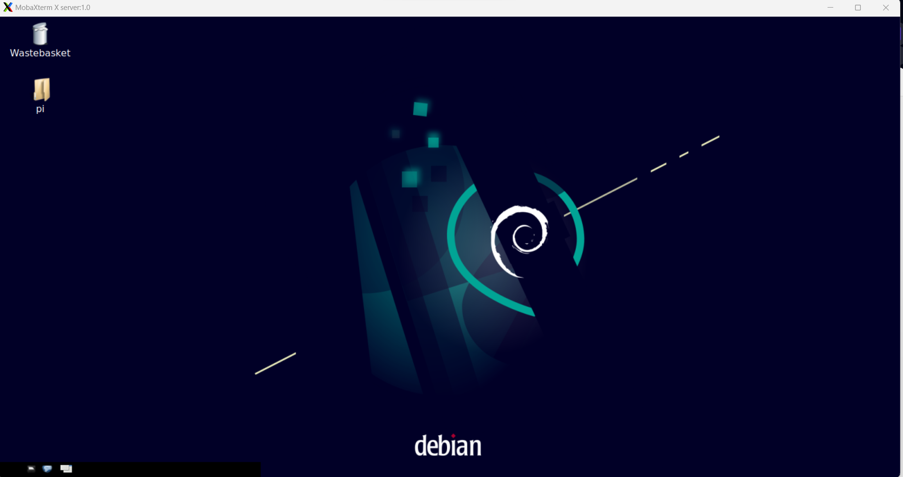
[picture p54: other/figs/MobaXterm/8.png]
   <p align="center" Style="font-size:12px; color:grey; font-type:italic;"><i> Figure 11: RaspberryPi LXDE desktop </i></p>

- Update Raspberry Pi, enter the following commands in order, this step make take some time:

   1- ```sudo apt update``` 

   2- ```sudo apt upgrade```

### Raspberry Pi Camera Activation

- One last step is to turn on Raspberry Pi camera. Write the command below in the terminal:

   ```sudo raspi-config```

- The window of Raspberry Pi settings will be opened, use arrow keys to move the cursor between the options. Choose the option with label "Interfacing Options" by pressing "Enter" key:

  ![MobaXterm](/other/figs/RaspberryPiOS/cam1.png)<p align="center" Style="font-size:12px; color:grey; font-type:italic;"><i> Figure 12: Interfacing Options </i></p>

- Now choose camera and press "Enter", the camera is activated now.
  
    ![MobaXterm](/other/figs/RaspberryPiOS/cam2.png)

    ![MobaXterm](/other/figs/RaspberryPiOS/cam3.png)<p align="center" Style="font-size:12px; color:grey; font-type:italic;"><i> Figure 13+14:Choosing camera option </i></p>

- After finishing the previous steps, press "ESC" to return to the original terminal, and enter the command below:
 
  ```sudo reboot```

### Installing Arduino IDE on Raspberry Pi

- Arduino IDE installation steps are straightforward. Open the terminal by clicking on the terminal icon or by using the shortcut Ctrl+Alt+T, then enter the following command:

   ```sudo apt install arduino```

- Before using the IDE, setting the permissions for the Arduino port in Raspberry Pi is needed:
Connect the Arduino to the Raspberry Pi using a USB cable. In the terminal on the Raspberry Pi, type the following command to list the available ports on your Raspberry Pi:
  
   ```ls /dev/tty*```

- This command will display a list of devices, and the Arduino port should be listed as something like `/dev/ttyACM0` or `/dev/ttyUSB0`. Note down the port name as you will need it for the next step. By default, the serial ports in Raspberry Pi are not accessible to regular users. To grant access to the Arduino port, you can use the chmod command to change the permissions of the port. Run the following command, replacing /dev/ttyACM0 with the actual port name you obtained:

   ```sudo chmod a+rw /dev/ttyACM0```

- After running the chmod command, you should now have the necessary permissions to access the Arduino port, and you are ready to use the arduino with the raspberry pi. To use the Arduino IDE, you can easily access it in the programming tab as in the image below:
   
   ![Settings Configuration](/other/figs/MobaXterm/34.png)<p align="center" Style="font-size:12px; color:grey; font-type:italic;"><i> Figure 15:Open programming tab and click Arduino icon </i></p>

- A window will open like the one below:

   ![Settings Configuration](/other/figs/MobaXterm/11.png)<p align="center" Style="font-size:12px; color:grey; font-type:italic;"><i> Figure 16:Ardunio IDE interface</i></p>

### Downloading OpenCV PySerial library

- PySerial library is essntial component to establish a succeful connection between Arduino and Raspberry Pi, it can be easily downloaded using the following command below:

   ```sudo apt-get install python-serial```

### Downloading OpenCV library on Raspberry Pi

We will be using OpenCV library, which stands for (Open Source Computer Vision Library). OpenCV is a popular open-source computer vision and machine learning library. It provides a vast collection of functions and algorithms for image and video processing, object detection and tracking, feature extraction, and more.

- OpenCv library isn't installed by default on the Raspberry Pi, you will have to install it. Open the terminal, and type the following command:

   ``` sudo apt-get install python3-opencv```
- Wait till the installation is done, when it is done, open any code editor, which can be found in the programming tab:
  
     ![Settings Configuration](/other/figs/MobaXterm/34.png)<p align="center" Style="font-size:12px; color:grey; font-type:italic;"><i> Figure 17:Open programming tab and click Geany icon</i></p>

- Choose Geany code editor for example. Geany is a simple and easy to use code editor (Try searching the internet for more details in case you want to know more), a window like this will be opened:
  
     ![Settings Configuration](/other/figs/MobaXterm/9.png)<p align="center" Style="font-size:12px; color:grey; font-type:italic;"><i> Figure 18:Geany editor interface </i></p>

- Import the library using the following command, and you are ready to use the library:

   ```import cv2```

---

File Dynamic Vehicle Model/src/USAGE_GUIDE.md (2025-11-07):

# Usage Guide: PID Tuning Simulation

## Quick Start

### Installation

1. **Install dependencies:**
   ```bash
   pip install -r requirements.txt
   ```

2. **Run the simulation:**
   ```bash
   python pid_tuning_sim.py
   ```

## Understanding the Simulation

### Bicycle Kinematic Model

The simulation implements a bicycle model with the following parameters:
- **Wheelbase (L)**: 0.15 m
- **Maximum steering angle**: ±30 degrees
- **Velocity**: 0.3 m/s (default)

### PID Control Law

The dual-error PID controller uses:

```python
correction = kp1 * angle_err + kp2 * dist_err
```

Where:
- `angle_err`: Heading error (rad) = desired_heading - current_heading
- `dist_err`: Lateral distance error (m) = d_right - d_left
- `kp1`: Gain for heading error (default: 0.5)
- `kp2`: Gain for lateral distance error (default: -0.75)

### Error Definitions

**1. Heading Error (angle_err):**
- Difference between desired and actual heading
- Positive: Robot heading left of desired
- Negative: Robot heading right of desired

**2. Lateral Distance Error (dist_err):**
- Deviation from track centerline
- Positive: Robot is left of centerline
- Negative: Robot is right of centerline
- Formula: `dist_err = d_right - d_left = -2 * (y - centerline_y)`

## Customizing the Simulation

### Modify Controller Parameters

Edit the `main()` function in `pid_tuning_sim.py`:

```python
results = run_simulation(
    kp1=0.5,          # Heading error gain
    kp2=-0.75,        # Lateral error gain
    velocity=0.3,      # Robot velocity (m/s)
    duration=15.0,     # Simulation time (s)
    initial_offset=0.2 # Initial lateral offset (m)
)
```

### Parameter Tuning Guidelines

**For kp1 (Heading Error Gain):**
- **Too low (< 0.3)**: Slow response, poor corner tracking
- **Optimal (0.4 - 0.6)**: Good tracking, minimal oscillation
- **Too high (> 0.7)**: Oscillations, overshoot

**For kp2 (Lateral Error Gain):**
- **Too low magnitude (> -0.5)**: Slow centering, wall proximity
- **Optimal (-0.6 to -0.9)**: Fast centering, stable
- **Too high magnitude (< -1.0)**: Oscillations, zigzag motion

## Interpreting Results

### Performance Metrics

The simulation outputs several metrics:

1. **Maximum Cross-Track Error**: Largest deviation from centerline
2. **Average Cross-Track Error**: Mean deviation over entire run
3. **Final Cross-Track Error**: Steady-state error
4. **Maximum Heading Error**: Largest orientation error
5. **Average Heading Error**: Mean orientation error

### Good Performance Indicators

- Max cross-track error < 10 cm
- Average cross-track error < 3 cm
- Final cross-track error < 2 cm
- No oscillations in plots
- Smooth steering input

## Output Plots

The simulation generates 6 plots:

1. **Robot Trajectory**: Top-down view of path
2. **Cross-Track Error**: Lateral deviation over time
3. **Heading Angle**: Orientation over time
4. **Steering Control**: Control input over time
5. **Error Components**: Heading and distance errors
6. **PID Correction**: Controller output

## Parameter Sensitivity Analysis

Run the built-in sensitivity analysis to see how parameters affect performance:

```python
parameter_sensitivity_analysis()
```

This tests:
- kp1: [0.3, 0.4, 0.5, 0.6, 0.7] with kp2 = -0.75
- kp2: [-0.5, -0.65, -0.75, -0.85, -1.0] with kp1 = 0.5

## Advanced Usage

### Add Derivative Control

Modify `DualErrorPIDController` class to include derivative terms:

```python
class DualErrorPIDController:
    def __init__(self, kp1=0.5, kp2=-0.75, kd1=0.1, kd2=-0.1):
        self.kp1, self.kp2 = kp1, kp2
        self.kd1, self.kd2 = kd1, kd2
        self.prev_angle_err = 0.0
        self.prev_dist_err = 0.0
    
    def compute_control(self, angle_err, dist_err, dt):
        # Proportional terms
        p_term = self.kp1 * angle_err + self.kp2 * dist_err
        
        # Derivative terms
        d_angle = (angle_err - self.prev_angle_err) / dt
        d_dist = (dist_err - self.prev_dist_err) / dt
        d_term = self.kd1 * d_angle + self.kd2 * d_dist
        
        correction = p_term + d_term
        
        # Update previous errors
        self.prev_angle_err = angle_err
        self.prev_dist_err = dist_err
        
        return correction
```

### Add Noise and Disturbances

Simulate sensor noise:

```python
def compute_errors_with_noise(self, robot_state, noise_std=0.01):
    angle_err, dist_err = self.compute_errors(robot_state)
    
    # Add Gaussian noise
    angle_err += np.random.normal(0, noise_std)
    dist_err += np.random.normal(0, noise_std)
    
    return angle_err, dist_err
```

## Troubleshooting

**Problem: Robot oscillates heavily**
- Solution: Reduce kp1 and/or increase kd1 (if using derivative)

**Problem: Robot doesn't center on track**
- Solution: Increase magnitude of kp2 (more negative)

**Problem: Robot drifts slowly**
- Solution: Increase kp1 or add integral term

**Problem: Robot overshoots corrections**
- Solution: Add derivative terms (kd1, kd2)

## References

For theoretical background, see the Dynamic Vehicle Model README.md file which includes:
- Bicycle kinematic model equations
- Ackermann steering geometry
- PID control theory
- Academic references

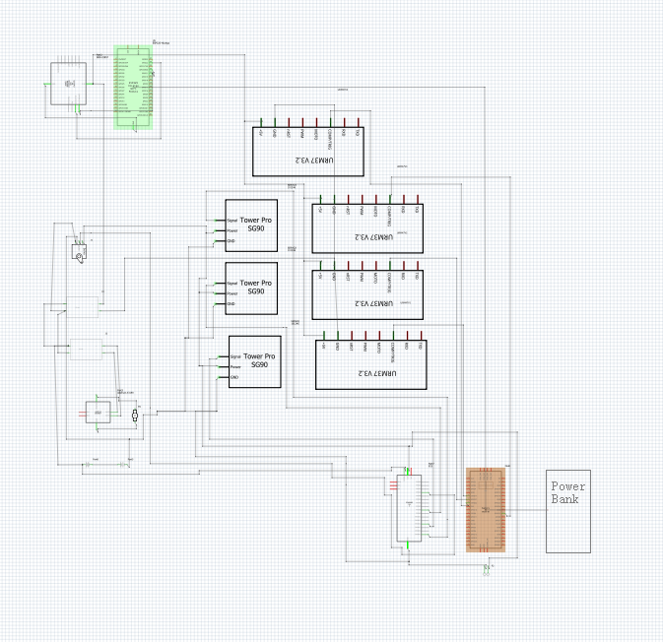
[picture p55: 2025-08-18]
other/figs/wiring.png

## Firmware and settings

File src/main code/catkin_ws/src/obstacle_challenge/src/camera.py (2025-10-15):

import rospy
from obstacle_challenge.srv import PillarDetection, PillarDetectionResponse
from obstacle_challenge.msg import Pillar
from picamera2 import Picamera2
import time
import cv2
import numpy as np

sec = 0  # Global counter for saving images (if enabled)

class PillarDetectionServer:
    def __init__(self):
        # Define image size for processing
        self.processing_width = 800
        self.processing_height = int(self.processing_width * 3*7/6/6)  # Maintain aspect ratio

        # Initialize PiCamera2
        self.picam2 = Picamera2()
        config = self.picam2.create_preview_configuration(main={'size': (3072, 1792)})
        config['main']['format'] = 'RGB888'  # Use RGB color format
        config['controls']['ExposureTime'] = 20000  # Manual exposure
        config['controls']['AnalogueGain'] = 7      # Manual gain
        self.picam2.configure(config)
        self.picam2.start()

        # Initialize ROS service
        self.service = rospy.Service('pillar_detection', PillarDetection, self.handle_detection_request)

    def detect_and_sort_pillars(self, image):
        # Convert image to HSV for easier color detection
        hsv = cv2.cvtColor(image, cv2.COLOR_RGB2HSV)

        # Define HSV color ranges for red, green, and pink
        lower_red2 = np.array([116, 61, 75])
        upper_red2 = np.array([172, 255, 255])

        lower_green = np.array([27, 61, 55])
        upper_green = np.array([68, 255, 255])

        lower_pink = np.array([126, 98, 44])
        upper_pink = np.array([134, 255, 255])

        # Create masks for each color
        mask_pink = cv2.inRange(hsv, lower_pink, upper_pink)
        mask_red = cv2.inRange(hsv, lower_red2, upper_red2)

        # Remove pink regions from red mask (to avoid overlap/misclassification)
        mask_red = cv2.bitwise_xor(mask_pink, mask_red)

        mask_green = cv2.inRange(hsv, lower_green, upper_green)

        # Clean masks using morphological operations (remove noise)
        kernel = np.ones((5, 5), np.uint8)
        cleaned_red = cv2.morphologyEx(mask_red, cv2.MORPH_OPEN, kernel)
        cleaned_red = cv2.morphologyEx(cleaned_red, cv2.MORPH_CLOSE, kernel)

        cleaned_green = cv2.morphologyEx(mask_green, cv2.MORPH_OPEN, kernel)
        cleaned_green = cv2.morphologyEx(cleaned_green, cv2.MORPH_CLOSE, kernel)

        # Find contours in the cleaned masks
        red_contours, _ = cv2.findContours(cleaned_red, cv2.RETR_EXTERNAL, cv2.CHAIN_APPROX_SIMPLE)
        green_contours, _ = cv2.findContours(cleaned_green, cv2.RETR_EXTERNAL, cv2.CHAIN_APPROX_SIMPLE)

        pillars = []  # List to store detected pillar data
        min_area = 100  # Ignore small contours (likely noise)

        # --- RED PILLAR DETECTION ---
        for contour in red_contours:
            area = cv2.contourArea(contour)
            if area < min_area:
                continue

            x, y, w, h = cv2.boundingRect(contour)
            if w == 0 or w > h:
                continue  # Ignore wide or flat contours

            # Calculate centroid and distance
            centroid_x = x + w // 2
            centroid_y = y + h // 2
            distance = np.sqrt((centroid_x - image.shape[1] // 2) ** 2 +
                               (centroid_y - image.shape[0] // 2) ** 2) / w
            distance = distance * 16.1454 + 9.4854  # Calibrated distance formula

            # Heuristic checks for shape and position
            if (abs(h / w - 2) > 0.3 and distance < 100 and abs(centroid_x - image.shape[1] // 2) < 40) or \
               (abs(area / (w * h)) < 0.75 and abs(centroid_x - image.shape[1] // 2) < 70):
                # Try a slightly shifted centroid_y to improve detection
                centroid_y += 10
                distance = np.sqrt((centroid_x - image.shape[1] // 2) ** 2 +
                                   (centroid_y - image.shape[0] // 2) ** 2) / w
                distance = distance * 16.1454 + 9.4854
                pillars.append((centroid_x, centroid_y, distance, 'red'))
                centroid_y -= 20  # Try another shift in the opposite direction

            # Final pass with original centroid
            distance = np.sqrt((centroid_x - image.shape[1] // 2) ** 2 +
                               (centroid_y - image.shape[0] // 2) ** 2) / w
            distance = distance * 16.1454 + 9.4854
            pillars.append((centroid_x, centroid_y, distance, 'red'))

        # --- GREEN PILLAR DETECTION (same logic as above) ---
        for contour in green_contours:
            area = cv2.contourArea(contour)
            if area < min_area:
                continue

            x, y, w, h = cv2.boundingRect(contour)
            if w == 0:
                continue

            centroid_x = x + w // 2
            centroid_y = y + h // 2
            distance = np.sqrt((centroid_x - image.shape[1] // 2) ** 2 +
                               (centroid_y - image.shape[0] // 2) ** 2) / w
            distance = distance * 16.1454 + 9.4854

            if (abs(h / w - 2) > 0.3 and distance < 100 and abs(centroid_x - image.shape[1] // 2) < 40) or \
               (abs(area / (w * h)) < 0.75 and abs(centroid_x - image.shape[1] // 2) < 70):
                centroid_y += 10
                distance = np.sqrt((centroid_x - image.shape[1] // 2) ** 2 +
                                   (centroid_y - image.shape[0] // 2) ** 2) / w
                distance = distance * 16.1454 + 9.4854
                pillars.append((centroid_x, centroid_y, distance, 'green'))
                centroid_y -= 20

            distance = np.sqrt((centroid_x - image.shape[1] // 2) ** 2 +
                               (centroid_y - image.shape[0] // 2) ** 2) / w
            distance = distance * 16.1454 + 9.4854
            pillars.append((centroid_x, centroid_y, distance, 'green'))

        # Sort by distance (closer pillars first)
        pillars_sorted = sorted(pillars, key=lambda x: x[2])

        return pillars_sorted

    def handle_detection_request(self, req):
        try:
            global sec
            sec += 1

            # Capture image from camera
            frame = self.picam2.capture_array()

            # Resize for processing
            frame_bgr = cv2.resize(frame, (self.processing_width, self.processing_height))

            # Crop region of interest (ROI)
            start_y = 15
            start_x = 0
            width = self.processing_width
            height = self.processing_height - start_y
            frame_bgr = frame_bgr[start_y:start_y + height, start_x:start_x + width]

            # Detect pillars in the image
            pillars_sorted = self.detect_and_sort_pillars(frame_bgr)

            # Prepare response message
            response = PillarDetectionResponse()

            for centroid_x, centroid_y, distance, color in pillars_sorted:
                pillar = Pillar()
                pillar.centroid_x = centroid_x
                pillar.centroid_y = centroid_y
                pillar.distance = distance
                pillar.color = 1 if color == 'red' else 0
                response.pillars.append(pillar)

                # (Optional) Debug image visualization
                '''
                w = 10
                x = centroid_x - w // 2
                y = centroid_y - w // 2

                box_color = (0, 0, 255) if color == 'red' else (0, 255, 0)

                cv2.rectangle(frame_bgr, (x, y), (x + w, y + w), box_color, 2)
                cv2.putText(frame_bgr, f"{distance:.2f}", (x, y + w + 50),
                            cv2.FONT_HERSHEY_SIMPLEX, 0.5, box_color, 2)
                cv2.putText(frame_bgr, color, (x, y + w + 20),
                            cv2.FONT_HERSHEY_SIMPLEX, 0.5, box_color, 2)
                
                frame_rgb = cv2.cvtColor(frame_bgr, cv2.COLOR_BGR2RGB)
                # cv2.imwrite(f'/home/wro25/Desktop/Output_images/image{sec}.png', frame_rgb)
                '''
            return response

        except Exception as e:
            rospy.logerr(f"Error in pillar detection: {str(e)}")
            return PillarDetectionResponse()  # Return empty response on failure

    def shutdown(self):
        # Gracefully stop camera and close OpenCV windows
        self.picam2.stop()
        cv2.destroyAllWindows()

if __name__ == "__main__":
    # Initialize ROS node
    rospy.init_node('pillar_detection_server')

    # Create and run detection server
    server = PillarDetectionServer()

    # Ensure shutdown is clean on exit
    rospy.on_shutdown(server.shutdown)

    # Keep node running
    rospy.spin()

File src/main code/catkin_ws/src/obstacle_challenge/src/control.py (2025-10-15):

import rospy
from std_msgs.msg import Float32
from open_challenge.msg import ultraInfo

import rospy
from obstacle_challenge.srv import PillarDetection, PillarDetectionResponse
from obstacle_challenge.msg import Pillar
from picamera2 import Picamera2
import cv2
import numpy as np
import math 

import board
import busio

import time
import math
import serial

from adafruit_motor import servo
from adafruit_pca9685 import PCA9685

import RPi.GPIO as GPIO
from time import sleep

from obstacle_challenge.srv import PillarDetection, PillarDetectionRequest
import copy

# === GPIO / servo / steering configuration ===
IN1 = 18
IN2 = 12
left_servo = 11
right_servo = 12
front_servo = 15
ackerman_servo = 0 

delta = 0
front_delta = 0
left_midd = 85     # neutral or “straight” position for left servo
right_midd = 85   # same for right servo
front_midd = 90
ackerman_midd = 90        # the “center” angle for steering servo
max_steering = 38
min_steering = -76

# some state / section counters
sec = 0
dir1 = 1  # direction indicator: +1 or -1 for turning orientation

first_section = 1
first_section_color = 1
check_pillar = 1

prev_dist_err = 0
dist_err = 0

yaw_0 = 0
prev_yaw = 0
prev_yw = 0
unwrapped_yaw = 0
steering = 0

thr = [0, 0, 0, 0]

# sensor indices: r, l, f, b (right, left, front, back)
yaw = 360 * 3 + 1
r = 0
l = 1
f = 2
b = 3

outer = l if dir1 == 1 else r
inner = r if dir1 == 1 else l

# Setup GPIO for motor drive (DC)
GPIO.setwarnings(False)
GPIO.setup(IN1, GPIO.OUT)
GPIO.setup(IN2, GPIO.OUT)
pi_pwm1 = GPIO.PWM(IN1, 5000)
pi_pwm2 = GPIO.PWM(IN2, 5000)
pi_pwm1.start(0)
pi_pwm2.start(0)

# Setup I2C and servos (via PCA9685)
i2c_servo = board.I2C()  
pca = PCA9685(i2c_servo)
pca.frequency = 50
servo0 = servo.Servo(pca.channels[right_servo], min_pulse=700, max_pulse=2900)
servo1 = servo.Servo(pca.channels[left_servo], min_pulse=700, max_pulse=2900)
servo2 = servo.Servo(pca.channels[ackerman_servo], min_pulse=500, max_pulse=2550)
servo3 = servo.Servo(pca.channels[front_servo], min_pulse=700, max_pulse=2900)

# distance arrays and filtering buffers
dists = [0, 0, 0, 0]               # filtered/usable distances for r, l, f, b
prev_dists = [0, 0, 0, 0]
curr_dists = [0, 0, 0, 0]
filtered_dists = [0, 0, 0, 0]
prev_filtered_dists = [0, 0, 0, 0]
raw_dists = [0, 0, 0, 0]
prefix_sum = [0, 0, 0, 0]
prev_dif1 = [0, 0, 0, 0]
cnt = [0, 0, 0, 0]
c = 0
prev_filtered_dif1 = [0, 0, 0, 0]

# To store pillars detected in each section
pillars_array = []
pillars_positions = []

max_speed = 80
value = 125
far_cw_pillar = 0
correction = 0

# === Pillar detection client helper ===
def pillar_detection_client():
    """
    Call the 'pillar_detection' ROS service to detect pillars.
    Based on first section or later logic, filter or store the pillars list
    into pillars_array for further navigation decisions.
    """
    global check_pillar, first_section, first_section_color, pillars_array, far_cw_pillar
    if first_section == 0:
        # after the first section, wait and call the service
        rospy.wait_for_service('pillar_detection')
        try:
            pillar_detection = rospy.ServiceProxy('pillar_detection', PillarDetection)
            request = PillarDetectionRequest()
            response = pillar_detection(request)
            temp = []
            n = len(response.pillars)
            print(f'n: {n}')
            # Some filtering logic: if too many pillars or disparity is large or with background distance, prune
            if (n > 2) or ((response.pillars[n-1].distance - response.pillars[0].distance > value)
                           and response.pillars[0].distance + dists[b] < 90) \
               or (response.pillars[0].distance + dists[b] >= 90 and n == 2):
                m = 1 if n == 2 else 2
                for i in range(m):
                    temp.append(response.pillars[i])
            else:
                for i in range(n):
                    temp.append(response.pillars[i])
            pillars_array.append(temp)
        except rospy.ServiceException as e:
            print(f"Service call failed: {e}")
    else:
        # first section: simpler logic to decide if a pillar is present
        pillar_detection = rospy.ServiceProxy('pillar_detection', PillarDetection)
        request = PillarDetectionRequest()
        response = pillar_detection(request)
        # threshold distance depending on dir1
        di = 40 if dir1 == -1 else 90 
        if len(response.pillars) > 0:
            # if pillar is “far enough”, set check_pillar = 0 else 1
            check_pillar = 0 if response.pillars[0].distance > di else 1
            if di == 90 and response.pillars[0].distance > 40:
                far_cw_pillar = 1
            first_section = 0
            # record the color of the first pillar if in range
            first_section_color = response.pillars[0].color if response.pillars[0].distance < di else -1
        else:
            check_pillar = 0
            first_section = 0
        pillars_array.append([])

def clean_all():
    """ Stop motors and clean up GPIO on shutdown """
    move_dc(0, pi_pwm1, pi_pwm2)
    GPIO.cleanup()

def move_dc(speed, pi_pwm1, pi_pwm2):
    """
    Drive DC motors via PWM.
    Positive speed => forward, negative => reverse.
    Clip to max_speed.
    """
    speed = min(speed, max_speed)
    speed = max(speed, -max_speed)
    if speed > 0:
        pi_pwm1.ChangeDutyCycle(abs(speed))
        pi_pwm2.ChangeDutyCycle(0)
    else:
        pi_pwm2.ChangeDutyCycle(abs(speed))
        pi_pwm1.ChangeDutyCycle(0)

def move_servos(yaw):
    """
    Set servo angles based on yaw and steering (ackermann) and servo offsets.
    This sets left, right, front, and steering servos.
    """
    global steering, delta, front_delta, max_steering, min_steering
    
    angle0 = min(right_midd + yaw + delta, right_midd + 45 + delta)
    angle0 = max(angle0, right_midd - 45 + delta)
    
    angle1 = min(left_midd + yaw - delta, left_midd + 45 - delta)
    angle1 = max(angle1, left_midd - 45 - delta)
    
    angle2 = min(steering, max_steering)
    angle2 = max(angle2, min_steering)
    
    angle3 = min(front_midd + yaw + front_delta, front_midd + 55)
    angle3 = max(angle3, front_midd - 55)
    
    servo0.angle = angle0
    servo1.angle = angle1
    servo2.angle = round(ackerman_midd + angle2)
    servo3.angle = angle3
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

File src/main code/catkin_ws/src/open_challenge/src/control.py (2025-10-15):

import rospy
from std_msgs.msg import Float32
from open_challenge.msg import ultraInfo

import board
import busio
import time, math, serial, copy

from adafruit_motor import servo
from adafruit_pca9685 import PCA9685
import RPi.GPIO as GPIO
from time import sleep

# ----------------------- Hardware Pin Setup -----------------------
IN1 = 18
IN2 = 12
left_servo = 11
right_servo = 12
front_servo = 15
ackerman_servo = 0 

# ----------------------- Servo and Steering Constants -----------------------
delta=0
front_delta=0
left_midd = 85    # Center angle for left servo
right_midd = 85   # Center angle for right servo
front_midd = 90
ackerman_midd = 90
max_steering = 38
min_steering = -76

# ----------------------- Control & State Variables -----------------------
sec=0
dir1=0
prev_dist_err=0
dist_err = 0
prev_yaw = 0
prev_yw = 0
unwrapped_yaw = 0
yaw_0 = 0
correction = 0
steering = 0

# ----------------------- GPIO Setup for Motor Control -----------------------
GPIO.setwarnings(False)
GPIO.setup(IN1,GPIO.OUT)
GPIO.setup(IN2,GPIO.OUT)
pi_pwm1 = GPIO.PWM(IN1,5000)
pi_pwm2 = GPIO.PWM(IN2,5000)
pi_pwm1.start(0)
pi_pwm2.start(0)

# ----------------------- PCA9685 Servo Controller Setup -----------------------
i2c_servo = board.I2C()  
pca = PCA9685(i2c_servo)
pca.frequency = 50

# Initialize servo channels
servo0 = servo.Servo(pca.channels[right_servo], min_pulse=700, max_pulse=2900)
servo1 = servo.Servo(pca.channels[left_servo], min_pulse=700, max_pulse=2900)
servo2 = servo.Servo(pca.channels[ackerman_servo], min_pulse=500, max_pulse=2550)
servo3 = servo.Servo(pca.channels[front_servo], min_pulse=700, max_pulse=2900)

# ----------------------- Ultrasonic Distance Buffers -----------------------
dists = [0,0,0,0]
prev_dists = [0,0,0,0]
curr_dists = [0,0,0,0]
filtered_dists=[0,0,0,0]
prev_filtered_dists = [0,0,0,0]
raw_dists=[0,0,0,0]
prefix_sum = [0,0,0,0]
prev_dif1 = [0,0,0,0]
cnt=[0,0,0,0]
thr = [0,0,0,0]
c=0
prev_filtered_dif1 = [0,0,0,0]

# ----------------------- Sensor Indexes -----------------------
yaw = 360*3+1
r = 0   # right sensor
l = 1   # left sensor
f = 2   # front sensor
b = 3   # back sensor

max_speed = 94

# ----------------------- Utility Functions -----------------------

def clean_all():
    """Stop all motion and clean up GPIO."""
    move_dc(0,pi_pwm1,pi_pwm2)
    GPIO.cleanup()
    

def move_dc(speed,pi_pwm1,pi_pwm2):
    """Drive the DC motor forward or backward based on speed."""
    speed=min(speed,max_speed)
    speed=max(speed,-max_speed)
    if speed>0:
         pi_pwm1.ChangeDutyCycle(abs(speed))
         pi_pwm2.ChangeDutyCycle(0)
    else:
         pi_pwm2.ChangeDutyCycle(abs(speed))
         pi_pwm1.ChangeDutyCycle(0)
        

def move_servos(yaw):
    """Set servo angles based on current yaw and steering corrections."""
    global steering, delta, front_delta, max_steering, min_steering
    
    # Clamp servo angles within safe ranges
    angle0=min(right_midd+yaw+delta,right_midd+45+delta)
    angle0=max(angle0,right_midd-45+delta)
    
    angle1=min(left_midd+yaw-delta,left_midd+45-delta)
    angle1=max(angle1,left_midd-45-delta)
    
    angle2=min(steering, max_steering)
    angle2=max(angle2,min_steering)
    
    angle3=min(front_midd+yaw+front_delta,front_midd+55)
    angle3=max(angle3,front_midd-55)
    
    # Apply to servos
    servo0.angle=angle0
    servo1.angle=angle1
    servo2.angle=round(ackerman_midd+angle2)
    servo3.angle=angle3

def steering_angle(corr):
    """Compute Ackermann steering angle based on correction input."""
    l = 135
    w = 125
    if corr != 0:
        r = l/math.tan(math.radians(corr))
        phiin = math.degrees(l/(r-w/2))
    else:
        phiin = 0
    phiin = math.radians(phiin+23.578)
    xg = 50 - 25*math.tan(phiin)/(math.sqrt(1+(math.tan(phiin))**2))
    a = (1114 - xg**2 + (xg-50)**2 + 10*math.sqrt(625-(xg-50)**2))
    A = math.sqrt(900*xg**2+180**2)
    phi = math.degrees(math.atan(xg/6))-180
    ans = math.degrees(math.asin(a/A)) - phi - 90
    return -1*ans

def pid_control(kp1=0.5,kp2=-0.45,kd2=0,speed=max_speed,threshold=0,dists=[30]*4):
    """PID control loop to adjust steering and maintain distance balance."""
    global prev_dist_err,steering, dist_err
    dist_err = dists[l] - dists[r]+threshold*dir1
    angle_err=yaw+float(dir1*sec*90)
    corr=kp1*(angle_err)+(kp2*(dist_err)+kd2*(dist_err-prev_dist_err))*(abs(dist_err)>0)
    
    # Limit correction to safe range
    corr = max(min(corr,25),-25)
    
    steering = steering_angle(corr)
    print(corr, steering)
    move_dc(speed,pi_pwm1,pi_pwm2)

def factor():
    """Helper factor based on previous yaw changes."""
    if abs(prev_yw+float(dir1*sec*90))<2:
        return 0
    else:
        return (abs(yaw+float(dir1*sec*90))/abs(prev_yw+float(dir1*sec*90)))

def dists_filter(sens):
    """Filter noisy ultrasonic sensor data."""
    global dists, prev_dists, prev_dif1,prefix_sum,raw_dists,cnt, prev_filtered_dists, prev_filtered_dif1,filtered_dists, prev_yw, thr,prev_dist_err
    dif1 = raw_dists[sens]-prev_dists[sens]
    dif2 = dif1-prev_dif1[sens]
    thr[sens] = dif2*0.5 if cnt[sens]==0 else thr[sens]
    prefix_sum[sens]+=dif2

    # Apply a differential filter with thresholds
    if abs(prefix_sum[sens]) > abs(thr[sens]) and abs(dif2)>3:
        filtered_dists[sens]=copy.deepcopy(prev_filtered_dists[sens]+prev_filtered_dif1[sens]*factor())
        dists[sens] = copy.deepcopy(filtered_dists[sens]) if cnt[sens] == 0 else copy.deepcopy(raw_dists[sens])
        cnt[sens]+=1
    else:
        prefix_sum[sens] = 0
        cnt[sens] = 0
        dists[sens]=copy.deepcopy(raw_dists[sens])
        filtered_dists[sens] = copy.deepcopy(dists[sens])
    prev_yw = yaw
    prev_dif1[sens] = dif1
    prev_filtered_dif1[sens] = filtered_dists[sens] - prev_filtered_dists[sens]
    if abs(prev_filtered_dif1[sens])>7:
        prev_filtered_dif1[sens]=0

def callback(dist):
    """ROS callback for ultrasonic distance data."""
    global dists, prev_dists, prev_dif1,raw_dists, prev_filtered_dists, filtered_dists, c, f, dist_err, prev_dist_err
    prev_dists=copy.deepcopy(raw_dists)
    prev_filtered_dists=copy.deepcopy(filtered_dists)
    raw_dists = list(dist.nums)
    if c == 2:
        dists_filter(r)
        dists_filter(l)
        dists_filter(f)
        dists_filter(b)
    else:
        dists=copy.deepcopy(raw_dists)
        filtered_dists = copy.deepcopy(dists)
        c+=1
    prev_dist_err=dist_err

def callback1(data):
    """ROS callback for gyro sensor (yaw)."""
    global yaw,prev_yw, yaw_0, correction
    yaw = round(unwrap_yaw(data.data))-correction - yaw_0
    move_servos(yaw+float(dir1*sec*90))
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

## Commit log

2025-08-18 Create README.md
    3d printing models
2025-08-18 Add files via upload
    uploading 3d printing parts of the robot
    [cameraholder.STL, cameraholder2.STL, dc holder.STL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]
2025-08-18 Add files via upload
    uploading 3d printed parts
    [cameraholder.STL, cameraholder2.STL, dc holder.STL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]
2025-08-18 Add files via upload
    uploading CNC cut parts
    [additional.DXF, chassis.DXF, cooplerlego (6).DXF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]
2025-08-18 assembly-parts
    uploading 3D assembly of the robot
    [(8258)_62821a-DkBluishGray v1.sldprt, 56mm Wheel Normal Tread v1.SLDPRT]
2025-08-18 electrical-diagram
    uploading wiring diagram of the robot
    [wiring diagram.fzz]
2025-08-18 electrical-diagram
    uploading circuit design
2025-08-19 Update README.md
    adding circuit images to README
2025-08-19 circuit-images
    uploading circuit images
2025-08-22 Update README.md
    Add case photo for open challenge
2025-10-15 Update and rename motor_test.ino to motor_test.ino
2025-10-15 Rename src/main code/Arduino code/Open_Challenge/Open_Challenge.ino to src/Old Version/main code/Arduino code/Open_Challenge/Open_Challenge.ino
2025-10-15 Rename src/Old Version/main code/Arduino code/Open_Challenge/Open_Challenge.ino to src/Old Version main code/Arduino code/Open_Challenge/Open_Challenge.ino
2025-11-17 Adding the bno yaw angles publisher on ESP
